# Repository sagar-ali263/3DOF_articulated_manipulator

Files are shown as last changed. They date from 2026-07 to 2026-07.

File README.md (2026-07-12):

# 3-DOF Articulated Robotic Manipulator (3R Serial Arm)

A fully analyzed and hardware-implemented 3-revolute-joint serial manipulator, built as an independent robotics project. The project covers the complete pipeline: mechanical design, kinematic and dynamic derivation, MATLAB simulation/validation, and embedded PID control on real hardware.

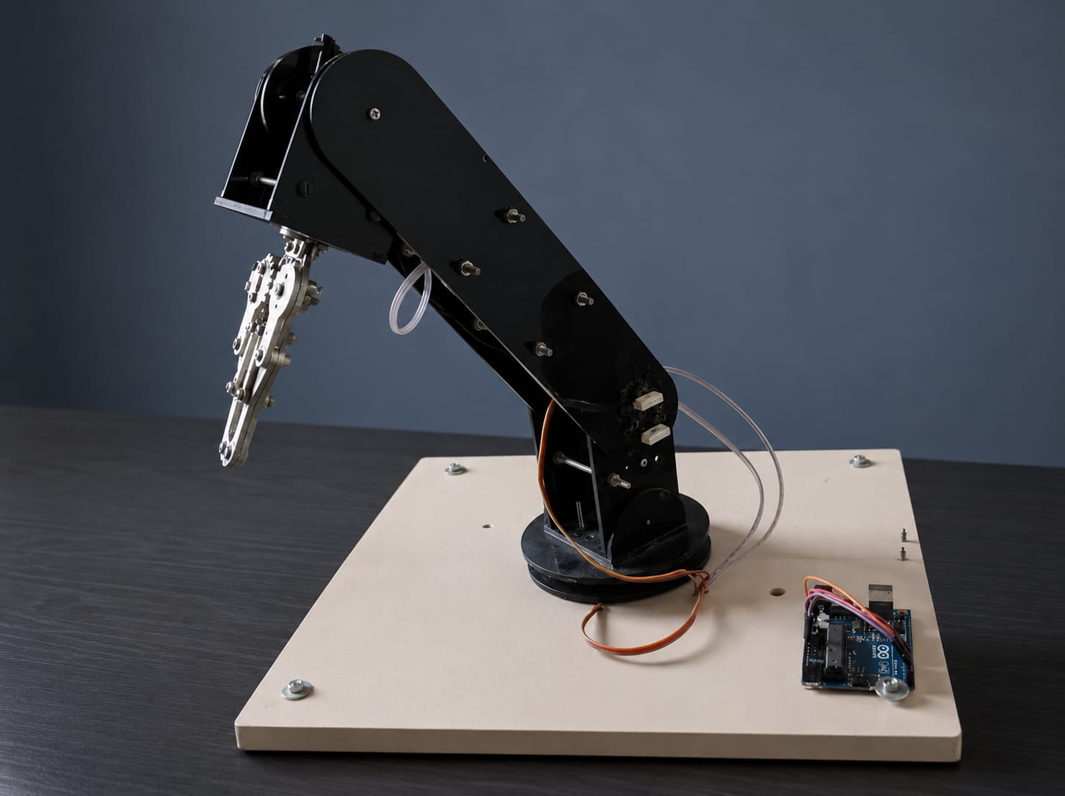
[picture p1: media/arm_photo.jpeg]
3DOF Manipulator


## Overview

- **Configuration:** RRR (3 revolute joints), open serial chain
- **Max vertical reach:** 470 mm
- **Actuators:** 3x MG995 metal gear servos (9.4 kg·cm @ 6V)
- **Controller:** ESP32, PWM servo control via the `ledc` peripheral (50 Hz, 14-bit resolution)
- **Design software:** SolidWorks (CAD/assembly), MATLAB Robotics System Toolbox (simulation), Arduino IDE (firmware)

## What's in this repo

| Folder | Contents |
|---|---|
| `cad/` | SolidWorks part/assembly files and STEP exports |
| `matlab/` | Kinematic, Jacobian, and dynamic simulation/validation scripts |
| `firmware/` | ESP32 Arduino code for PWM joint control |
| `docs/` | Full project report (PDF) with complete derivations |
| `media/` | Photos and demo video/GIF of the physical build |

## Technical Highlights

**Kinematics**
- Forward kinematics derived analytically using the Denavit-Hartenberg convention and homogeneous transformation matrices
- Verified against MATLAB's `rigidBodyTree` model, cross-checked at multiple joint-angle test configurations

**Jacobian and Singularity Analysis**
- Full geometric Jacobian derived manually (skew-symmetric matrix method) and independently verified against MATLAB's built-in `geometricJacobian`
- Two singularity conditions identified through determinant analysis: an elbow singularity (fully extended/folded arm) and a workspace-boundary singularity (end-effector on the vertical axis)
- Manipulability index (`w = sqrt(det(Jv * Jv'))`) computed across the reachable workspace to visualize dexterity and flag near-singular regions

**Dynamics**
- Full equations of motion derived via the Euler-Lagrange formulation, including per-link inertia tensors (parallel-axis theorem), the 3x3 mass matrix, Coriolis/centrifugal terms, and the gravity vector
- Mass matrix verified in MATLAB for symmetry and positive definiteness
- Joint torques (tau1, tau2, tau3) computed and cross-checked against the analytical derivation for a test trajectory

**Control**
- Joint-space PID control implemented on ESP32, mapping target joint angles to PWM pulse width (500-2500 microseconds)
- Software joint-limit enforcement and safe home-position initialization on power-up
- `checkTrajectoryPoint.m` used to reject unsafe trajectory waypoints that approach a singular configuration before sending them to hardware

## Validation Approach

Every analytical result in this project (forward kinematics, Jacobian, mass matrix, gravity vector, joint torques) was independently cross-checked against MATLAB's Robotics System Toolbox before being trusted, and the maximum numerical error was printed at each validation step. This was done deliberately: since the hardware implementation depends on this model being correct, each stage had to pass validation before moving to the next.

## Tools Used

SolidWorks - MATLAB (Robotics System Toolbox) - Arduino IDE - ESP32

## Full Report

See [`docs/`](./docs) for the complete project report, including all derivations, experimental workspace/manipulability plots, and the economic/safety/educational analysis.

---

*Sagar Ali - BS Mechatronics and Control Engineering, UET Lahore (Faisalabad Campus)*

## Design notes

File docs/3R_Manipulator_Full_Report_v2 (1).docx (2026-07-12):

UNIVERSITY LABORATORY REPORT

Design, Analysis and Fabrication of a

3R Serial Robotic Manipulator Arm

Submitted by:

[Student Name]

[Registration No.]

Supervised by:

[Supervisor Name]

Department of Mechatronics Engineering

May 2026

1. Key Characteristics

The manipulator under study is a three-revolute-joint (3R) serial robotic arm. Each joint is an actuated revolute joint making this a fully rotational, open-chain mechanism with three degrees of freedom. The principal characteristics are summarised in Table 1.

Table 1: Key Characteristics of the 3R Manipulator

Parameter | Value / Description
Configuration | RRR — three revolute joints in series (serial chain)
Degrees of Freedom | 3
Joint 1 — θ₁ | Rotation about vertical Z₀ axis (base rotation), range: 0° – 180°
Joint 2 — θ₂ | Rotation about horizontal Z₁ axis (shoulder), range: 0° – 180°
Joint 3 — θ₃ | Rotation about Z₂ axis (elbow), range: 0° – 180°
Base Height (d₁) | 90 mm — vertical offset from base frame to shoulder joint
Link 2 Length (l₂) | 210 mm
Link 3 Length (l₃) | 170 mm (includes end-effector body)
Maximum Reach | 380 mm from shoulder (l₂ + l₃, arm fully extended)
Minimum Reach | 40 mm (|l₂ − l₃|, arm fully folded)
End-Effector | Point at tip of Link 3 — no gripper
Actuators | MG995 Metal Gear Servo Motors × 3 (torque: 9.4 kg·cm @ 6 V)
Controller | ESP32 Microcontroller — PWM via ledc peripheral
Link Material | Acrylic (PMMA) sheet, 5 mm thick, ρ ≈ 1180 kg/m³
Design Software | SolidWorks
Analysis Software | MATLAB
Firmware IDE | Arduino IDE

2. Design

2.1 Mechanical Structure

The 3R manipulator consists of a fixed acrylic base plate, three MG995 servo motors acting as revolute joints, two flat acrylic link bars, and a point end-effector at the tip of Link 3. The base servo (Joint 1) is mounted vertically and rotates the entire arm assembly about the Z₀ axis. Link 1 is the rigid vertical column of height d₁ = 90 mm connecting the base to Joint 2. Link 2 (l₂ = 210 mm) is a flat acrylic bar connecting Joint 2 to Joint 3. Link 3 (l₃ = 170 mm) extends from Joint 3 to the end-effector point. A gripper-like profile visible at the end of Link 3 in the SolidWorks model is a structural feature of Link 3 only and carries no functional gripper purpose. All links are machined from 5 mm thick acrylic sheet.

[ INSERT IMAGE HERE ]

Figure 1: SolidWorks Assembly — 3R Manipulator (Isometric View)

2.2 Frame Assignment

Coordinate frames are assigned following the standard Denavit-Hartenberg convention. The Z-axis of each frame coincides with the joint rotation axis. The symbol ⊗ in the design sketches denotes a Z-axis directed out of the plane, confirming that Z₁ and Z₂ are horizontal and parallel. The base frame Z₀ points vertically upward.

[ INSERT IMAGE HERE ]

Figure 2: DH Frame Assignment Sketch (Side View with Z-axes and Origins labelled)

2.3 Home / Reference Configuration

Before executing any motion task the manipulator is driven to a fixed reference pose known as the home configuration. This ensures a consistent and safe starting state from which all trajectories are planned. The home joint angles are:

θ_1 = 0°, θ_2 = 0°, θ_3 = 90°

Substituting into the forward kinematics equations (derived in Section 4):

x = cos 0° · (210 cos 0° + 170 cos 90°) = 1 · (210 + 0) = 210 mm

y = sin 0° · (210 cos 0° + 170 cos 90°) = 0 mm

z = 90 + 210 sin 0° + 170 sin 90° = 90 + 0 + 170 = 260 mm

The end-effector point is therefore located at (210, 0, 260) mm in the base frame at the home position. Table 2 gives the corresponding PWM initialisation values for the ESP32.

Table 2: PWM Values at Home Configuration

Joint | Home Angle | PWM Pulse Width
Joint 1 (θ₁) | 0° | 500 μs
Joint 2 (θ₂) | 0° | 500 μs
Joint 3 (θ₃) | 90° | 1500 μs

The PWM frame frequency is 50 Hz. Pulse widths range from 500 μs (0°) to 2500 μs (180°) across all three servos. On power-up the ESP32 drives all channels to home values before accepting any motion commands.

[ INSERT IMAGE HERE ]

Figure 3: SolidWorks — Home Configuration (θ₁=0°, θ₂=0°, θ₃=90°) Side View

3. Homogeneous Transformation Matrices

A homogeneous transformation matrix T ∈ ℝ⁴ˣ⁴ encodes the rotation and translation from one coordinate frame to the adjacent frame. Using the standard Denavit-Hartenberg convention, the transformation between frames i−1 and i is:

T_(i−1)^i = Rot(Z, θ_i ) · Trans(Z, d_i ) · Trans(X, a_i ) · Rot(X, α_i )

Expanding into matrix form, where cθ = cosθ, sθ = sinθ, cα = cosα, sα = sinα:

T = [cθᵢ, −sθᵢcαᵢ, sθᵢsαᵢ, aᵢcθᵢsθᵢ, cθᵢcαᵢ, −cθᵢsαᵢ, aᵢsθᵢ0, sαᵢ, cαᵢ, dᵢ0, 0, 0, 1]

The shorthand notation cᵢ = cosθᵢ, sᵢ = sinθᵢ, c₂₃ = cos(θ₂+θ₃), s₂₃ = sin(θ₂+θ₃) is used throughout.

3.1 Individual Transformation Matrix T₀¹ (Joint 1)

Parameters: a₁ = 0, α₁ = 90° ⟹ cosα₁ = 0, sinα₁ = 1, d₁ = 90 mm, θ₁ variable.

⁰T₁ = [c₁, 0, s₁, 0s₁, 0, −c₁, 00, 1, 0, 900, 0, 0, 1]

3.2 Individual Transformation Matrix T₁² (Joint 2)

Parameters: a₂ = 210 mm, α₂ = 0° ⟹ cosα₂ = 1, sinα₂ = 0, d₂ = 0, θ₂ variable.

¹T² = [c₂, −s₂, 0, 210c₂s₂, c₂, 0, 210s₂0, 0, 1, 00, 0, 0, 1]

3.3 Individual Transformation Matrix T₂³ (Joint 3)

Parameters: a₃ = 170 mm, α₃ = 0°, d₃ = 0, θ₃ variable.

²T³ = [c₃, −s₃, 0, 170c₃s₃, c₃, 0, 170s₃0, 0, 1, 00, 0, 0, 1]

3.4 Cumulative Matrix ⁰T² = ⁰T¹ · ¹T²

Multiplying row by column and applying c₁c₂ − s₁s₂ = c₂₃ where appropriate:

Element-by-element computation (row 1, column 1):

R(1,1) = c₁·c₂ + 0·s₂ + s₁·0 = c₁c₂

Element (1,4) — position x:

p_x = c₁·210c₂ + 0·210s₂ + s₁·0 + 0 = 210c₁c₂

Element (3,4) — position z:

p_z = 0·210c₂ + 1·210s₂ + 0·0 + 90 = 210s₂ + 90

Full result:

⁰T² = [c₁c₂, −c₁s₂, s₁, 210c₁c₂s₁c₂, −s₁s₂, −c₁, 210s₁c₂s₂, c₂, 0, 210s₂+900, 0, 0, 1]

3.5 Full End-Effector Transform ⁰T³ = ⁰T² · ²T³

Multiplying ⁰T² by ²T³. Using the angle-sum identities:

c₂c₃ − s₂s₃ = cos(θ₂+θ₃) = c₂₃

s₂c₃ + c₂s₃ = sin(θ₂+θ₃) = s₂₃

Key element computations:

R(1,1) = c₁c₂·c₃ + (−c₁s₂)·s₃ = c₁(c₂c₃−s₂s₃) = c₁c₂₃

R(1,2) = c₁c₂·(−s₃) + (−c₁s₂)·c₃ = −c₁(c₂s₃+s₂c₃) = −c₁s₂₃

p_x = 170c₁(c₂c₃−s₂s₃) + 210c₁c₂ = c₁(210c₂ + 170c₂₃)

p_z = 170(s₂c₃+c₂s₃) + 210s₂ + 90 = 90 + 210s₂ + 170s₂₃

Final result:

⁰T³ = [c₁c₂₃, −c₁s₂₃, s₁, c₁(210c₂+170c₂₃)s₁c₂₃, −s₁s₂₃, −c₁, s₁(210c₂+170c₂₃)s₂₃, c₂₃, 0, 90+210s₂+170s₂₃0, 0, 0, 1]

4. Forward Position Kinematics

Forward kinematics maps a set of joint angles (θ₁, θ₂, θ₃) to the Cartesian position (x, y, z) of the end-effector point O₃ in the base frame. The position is extracted from the fourth column of ⁰T³.

4.1 DH Parameter Table

Table 3: Denavit-Hartenberg Parameters

Joint i | aᵢ (mm) | αᵢ (deg) | dᵢ (mm) | θᵢ (variable)
1 | 0 | 90° | d₁ = 90 | θ₁* (0° – 180°)
2 | l₂ = 210 | 0° | 0 | θ₂* (0° – 180°)
3 | l₃ = 170 | 0° | 0 | θ₃* (0° – 180°)

The asterisk (*) marks the variable (active) joint parameter. All remaining entries in each row are constant geometric properties of the link.

4.2 Forward Kinematics Equations

Extracting the position column of ⁰T³, the end-effector position O₃ is:

x = c_1 · (210c_2 + 170c_23 )

y = s_1 · (210c_2 + 170c_23 )

z = 90 + 210s_2 + 170s_23

The x and y coordinates share the same horizontal radius r = 210c₂ + 170c₂₃, scaled by cosθ₁ and sinθ₁ respectively. This confirms that joint 1 sweeps the arm through the horizontal plane while joints 2 and 3 control vertical elevation.

4.3 Verification at Home Configuration

At θ₁ = 0°, θ₂ = 0°, θ₃ = 90° (home position):

x = cos0°·(210cos0° + 170cos90°) = 1·(210 + 0) = 210 mm

y = sin0°·(210cos0° + 170cos90°) = 0 mm

z = 90 + 210sin0° + 170sin90° = 90 + 0 + 170 = 260 mm

Result: O₃ = (210, 0, 260) mm — consistent with the home configuration derived in Section 2.3.

5. Inverse Position Kinematics

Inverse kinematics (IK) computes the joint angles (θ₁, θ₂, θ₃) given a desired end-effector position (x_d, y_d, z_d). Two complementary approaches are presented below.

Define the following intermediate variables used by both approaches:

r = √(x^2 ₝ + y^2 ₞) [horizontal distance from Z₀ axis]

s = z_d − d_1 = z_d − 90 [height above Joint 2]

5.1 Algebraic Approach

Step 1 — Solve for θ₁

From the FK equations x = c₁·r and y = s₁·r. Dividing y by x:

tanθ_1 = (y_d)/(x_d)

θ_1 = atan2 (y_d , x_d )

The four-quadrant atan2 function is used to correctly handle all quadrants. The joint range 0°–180° restricts valid solutions to y_d ≥ 0.

Step 2 — Solve for θ₃

Squaring and adding the planar FK equations for r and s:

r = 210c_2 + 170c_23

s = 210s_2 + 170s_23

r^2 + s^2 = (210c_2 +170c_23 )^2 + (210s_2 +170s_23 )^2

Expanding and collecting using c₂c₂₃ + s₂s₂₃ = cos(θ₃):

= 210² + 170² + 2·210·170·cosθ₃

= 44100 + 28900 + 71400 cosθ₃

= 73000 + 71400 cosθ₃

Therefore:

cosθ_3 = (r^2 + s^2 − 73000)/71400

θ_3 = ± arccos[(r^2 + s^2 − 73000)/71400]

Two solutions exist: θ₃ > 0 (elbow-up) and θ₃ < 0 (elbow-down). A real solution exists only when |cosθ₃| ≤ 1, i.e. the target lies within the reachable workspace.

Step 3 — Solve for θ₂ (algebraic substitution)

Expanding the FK equations for r and s with θ₃ now known:

r = (210 + 170c₃)c₂ − 170s₃·s₂ = k₁c₂ − k₂s₂

s = (210 + 170c₃)s₂ + 170s₃·c₂ = k₁s₂ + k₂c₂

where the substitution constants are:

k_1 = 210 + 170c_3

k_2 = 170s_3

Solving simultaneously:

θ_2 = atan2(k_1 s − k_2 r , k_1 r + k_2 s)

5.2 Geometric Approach

Step 1 — θ₁ (identical to algebraic)

θ_1 = atan2(y_d , x_d )

Step 2 — Distance D and θ₃ via Law of Cosines

In the vertical (r, s) plane, D is the distance from Joint 2 to the end-effector:

D = √(r^2 + s^2)

Applying the law of cosines to the triangle with sides l₂, l₃ and hypotenuse D:

D² = l₂² + l₃² − 2l₂l₃cos(180°−θ₃) = 44100 + 28900 + 71400cosθ₃

cosθ_3 = (D^2 − 73000)/71400

Step 3 — Angles β and γ for θ₂

β is the elevation angle of the line from Joint 2 to the end-effector:

β = atan2(s , r)

γ is the interior angle at Joint 2, from the law of cosines:

cosγ = (l^2 ₂ + D^2 − l^2 ₃)/(2l_2 D) = (D^2 + 15200)/(420D)

γ = arccos[(D^2 + 15200)/(420D)]

The shoulder angle θ₂ is then:

θ_2 = β − γ [elbow-up solution]

θ_2 = β + γ [elbow-down solution]

6. Velocity Kinematics

Velocity kinematics relates joint angular velocities to the linear and angular velocity of the end-effector through the Jacobian matrix J. The explicit geometric Jacobian method is used, following the instructor’s step-by-step procedure.

[ṻₑωₑ] = J · [θ̇₁θ̇₂θ̇₃]

6.1 Step 1: Extract Z-axis Vectors from Cumulative T Matrices

The Z-axis vector Zᵢ is the third column of the rotation sub-matrix of ⁰Tᵢ. From the matrices derived in Section 3:

Z_0 = [001]

(base frame Z-axis, pointing vertically upward)

Z_1 = Third column of R in ⁰T¹ = [s_1 −c_1 0]

Z_2 = Third column of R in ⁰T² = [s_1 −c_1 0]

Note: Z₁ = Z₂ because α₂ = 0° introduces no twist between frames 1 and 2.

6.2 Step 2: Extract Origin Vectors from Cumulative T Matrices

The origin Oᵢ is the fourth column (position vector) of ⁰Tᵢ:

O_0 = [000]

O_1 = [0090]

O_2 = [210c_1 c_2 210s_1 c_2 90 + 210s_2 ]

End-effector origin (from ⁰T³):

O_3 = [c_1 (210c_2 +170c_23 )s_1 (210c_2 +170c_23 )90+210s_2 +170s_23 ]

6.3 Step 3: Skew-Symmetric Matrices S(Z)

The instructor requires that the cross product Z × v be written as S(Z)·v, where the skew-symmetric matrix of Z = [z_x, z_y, z_z]ᵀ is:

S(Z) = [0, −z_z, z_yz_z, 0, −z_x−z_y, z_x, 0]

S(Z₀) — for Joint 1

Z₀ = [0, 0, 1]ᵀ ⟹ z_x=0, z_y=0, z_z=1

S(Z₀) = [0, − 1, 01, 0, 00, 0, 0]

S(Z₁) — for Joint 2

Z₁ = [s₁, −c₁, 0]ᵀ ⟹ z_x=s₁, z_y=−c₁, z_z=0

S(Z₁) = [0, 0, −c₁0, 0, −s₁c₁, s₁, 0]

S(Z₂) — for Joint 3

Z₂ = [s₁, −c₁, 0]ᵀ (same as Z₁)

S(Z₂) = S(Z₁) = [0, 0, −c₁0, 0, −s₁c₁, s₁, 0]

6.4 Step 4: Compute O₃ − Oᵢ (Full Subtraction, No Premature Cancellation)

Let P = 210c₂ + 170c₂₃ and Q = 210s₂ + 170s₂₃ for conciseness.

O₃ − O₀

O_3 − O_0 = [c_1 P − 0s_1 P − 090+Q − 0]

= [c_1 Ps_1 P90 + Q]

O₃ − O₁

O_3 − O_1 = [c_1 P − 0s_1 P − 0(90+Q) − 90]

= [c_1 Ps_1 PQ]

O₃ − O₂

O_3 − O_2 = [c_1 (210c₂+170c₂₃) − 210c_1 c_2 s_1 (210c₂+170c₂₃) − 210s_1 c_2 (90+Q) − (90+210s₂)]

Expanding and grouping identical terms:

Row 1: 210c₁c₂ + 170c₁c₂₃ − 210c₁c₂ = (210c₁c₂ − 210c₁c₂) + 170c₁c₂₃ = 170c₁c₂₃

Row 2: 210s₁c₂ + 170s₁c₂₃ − 210s₁c₂ = (210s₁c₂ − 210s₁c₂) + 170s₁c₂₃ = 170s₁c₂₃

Row 3: 90+210s₂+170s₂₃−90−210s₂ = (90−90)+(210s₂−210s₂)+170s₂₃ = 170s₂₃

O_3 − O_2 = [170c_1 c_23 170s_1 c_23 170s_23 ]

6.5 Step 5: Compute Linear Jacobian Columns Jᵥᵢ = S(Zᵢ₋₁)(O₃−Oᵢ₋₁)

Column 1: Jᵥ₁ = S(Z₀)(O₃−O₀)

Performing the matrix–vector multiplication row by row:

Row 1: (0)(c₁P) + (−1)(s₁P) + (0)(90+Q) = −s₁P

Row 2: (1)(c₁P) + (0)(s₁P) + (0)(90+Q) = c₁P

Row 3: (0)(c₁P) + (0)(s₁P) + (0)(90+Q) = 0

J_(v1) = [−s₁P c₁P 0]

Column 2: Jᵥ₂ = S(Z₁)(O₃−O₁)

Row 1: (0)(c₁P) + (0)(s₁P) + (−c₁)(Q) = −c₁Q

Row 2: (0)(c₁P) + (0)(s₁P) + (−s₁)(Q) = −s₁Q

Row 3: (c₁)(c₁P) + (s₁)(s₁P) + (0)(Q) = c^2 ₁P + s^2 ₁P = P

J_(v2) = [−c₁Q−s₁Q P]

Column 3: Jᵥ₃ = S(Z₂)(O₃−O₂)

Row 1: (0)(170c₁c₂₃) + (0)(170s₁c₂₃) + (−c₁)(170s₂₃) = −170c₁s₂₃

Row 2: (0)(170c₁c₂₃) + (0)(170s₁c₂₃) + (−s₁)(170s₂₃) = −170s₁s₂₃

Row 3: (c₁)(170c₁c₂₃) + (s₁)(170s₁c₂₃) + (0)(170s₂₃) = 170c₂₃(c^2 ₁+s^2 ₁) = 170c₂₃

J_(v3) = [−170c₁s₂₃−170s₁s₂₃ 170c₂₃]

6.6 Step 6: Angular Jacobian Columns Jωᵢ = Zᵢ₋₁

For revolute joints the angular velocity contribution is simply the Z-axis of the previous frame:

Jω₁ = Z₀ = [0, 0, 1]ᵀ

Jω₂ = Z₁ = [s₁, −c₁, 0]ᵀ

Jω₃ = Z₂ = [s₁, −c₁, 0]ᵀ

6.7 Step 7: Full Geometric Jacobian J (6 × 3)

Assembling all columns (P = 210c₂+170c₂₃, Q = 210s₂+170s₂₃):

J = [−s₁P, −c₁Q, −170c₁s₂₃c₁P, −s₁Q, −170s₁s₂₃0, P, 170c₂₃0, s₁, s₁0, −c₁, −c₁1, 0, 0]

The upper three rows form the linear velocity Jacobian Jᵥ and the lower three rows form the angular velocity Jacobian Jω.

6.8 Analytical (Linear Velocity) Jacobian Jᵥ (3 × 3)

Jᵥ = [−s₁P, −c₁Q, −170c₁s₂₃c₁P, −s₁Q, −170s₁s₂₃0, P, 170c₂₃]

6.9 Singularity Analysis

A singularity occurs when the Jacobian loses rank, i.e. det(Jᵥ) = 0. The arm cannot generate end-effector velocity in one or more directions at a singular configuration.

Determinant Calculation — Cofactor Expansion Along Row 3

det(Jᵥ) = 0·C₃₁ + P·C₃₂ + 170c₂₃·C₃₃

Computing cofactor C₃₂:

C₃₂ = (−1)⁵ · det[ [−s₁P, −170c₁s₂₃], [c₁P, −170s₁s₂₃] ]

= −1 · [ (−s₁P)(−170s₁s₂₃) − (−170c₁s₂₃)(c₁P) ]

= −1 · [ 170s^2 ₁Ps₂₃ + 170c^2 ₁Ps₂₃ ]

= −1 · 170Ps₂₃(s^2 ₁+c^2 ₁) = −170Ps₂₃

Computing cofactor C₃₃:

C₃₃ = (+1) · det[ [−s₁P, −c₁Q], [c₁P, −s₁Q] ]

= (−s₁P)(−s₁Q) − (−c₁Q)(c₁P) = s^2 ₁PQ + c^2 ₁PQ = PQ

Therefore:

det(Jᵥ) = P·(−170Ps₂₃) + 170c₂₃·PQ

= 170P(−Ps₂₃ + c₂₃Q)

= 170P [ c₂₃(210s₂+170s₂₃) − s₂₃(210c₂+170c₂₃) ]

= 170P · 210 [ c₂₃s₂ − s₂₃c₂ ]

= 170 · 210 · P · sin(θ₂ − (θ₂+θ₃))

= −35700 · P · sinθ₃

det(Jᵥ) = −35700 · (210c_2 + 170c_23 ) · sinθ_3

Singular Configurations

The determinant vanishes under two independent conditions:

Singularity 1 — Elbow Singularity:

sinθ_3 = 0 ⟹ θ_3 = 0° or 180°

At θ₃ = 0° the arm is fully extended; at θ₃ = 180° the arm is fully folded. Joints 2 and 3 become collinear and lose one degree of independent control.

Singularity 2 — Workspace Boundary (Axis Alignment):

P = 0 ⟹ 210c_2 + 170c_23 = 0

The end-effector lies on the vertical Z₀ axis (r = 0). The azimuthal angle θ₁ becomes undefined and joint 1 is singular.

7. Dynamics

The equation of motion of a rigid-body serial manipulator, derived from the Euler-Lagrange formulation, is:

M(q)äq + C(q, ̇q) ̇q + G(q) = τ

where q = [θ₁, θ₂, θ₃]ᵀ is the joint vector, M(q) is the 3×3 mass matrix, C(q,̇q) is the Coriolis and centrifugal matrix, G(q) is the gravity vector, and τ is the joint torque vector.

Note: Physical link masses are to be measured experimentally and will be substituted into the symbolic expressions below. Placeholder symbols m₂, m₃ denote link masses and I₂, I₃ denote link moments of inertia.

7.1 Inertia Tensor of Each Link

Each acrylic link is modelled as a uniform rectangular bar of length l, width w, and thickness t. The inertia tensor about the link centre of mass (COM), with axes aligned with the principal body axes, is derived by direct integration:

Iᴄᴹ = [m(w²+t²)/12, 0, 00, m(l²+t²)/12, 00, 0, m(l²+w²)/12]

For thin acrylic sheet (t = 5 mm ≪ l, w), terms involving t² are negligible. The dominant inertia components are:

Link 2 (l₂ = 210 mm, mass m₂, width w₂):

I_(2yy) ≈ (m_2 l^2 ₂)/12 = 3675m_2 mm²

I_(2zz) ≈ (m_2 (l^2 ₂+w^2 ₂))/12

Link 3 (l₃ = 170 mm, mass m₃, width w₃):

I_(3yy) ≈ (m_3 l^2 ₃)/12 = 2408.3m_3 mm²

By the parallel-axis theorem (shifting from COM to proximal joint end):

I_(2,joint) = (m_2 l^2 ₂)/12 + m_2 ((l_2)/2)^2 = (m_2 l^2 ₂)/3 = 14700m_2 mm²

I_(3,joint) = (m_3 l^2 ₃)/3 = 9633.3m_3 mm²

7.2 Mass Matrix M(q)

Using the Lagrangian formulation T = ½̇qᵀ M(q) ̇q, the mass matrix is computed from the squared velocities of the link centres of mass. The total translational kinetic energy is:

T = ½ m_2 |v_(C2) |^2 + ½ m_3 |v_(C3) |^2 + rotational terms

After computing squared COM speeds and collecting terms by joint velocity products, the 3×3 symmetric mass matrix M(q) is:

M(q) = [M₁₁, 0, 00, M₂₂, M₂₃0, M₃₂, M₃₃]

with elements:

M_11 = m_2 (105c_2 )^2 + m_3 (210c_2 +85c_23 )^2

M_22 = m_2 ·105² + m_3 (210² + 2·210·85·c_3 + 85²) + I_(2,joint)

M_33 = m_3 ·85² + I_(3,joint) = 7225m_3 + I_(3,joint)

M_23 = M_32 = m_3 (7225 + 17850c_3 )

M_12 = M_13 = 0

The block-diagonal structure (M₁₂ = M₁₃ = 0) arises because joint 1 rotation about the vertical Z₀ axis does not couple inertially with joints 2 and 3 in the rotational component. The coupling M₂₃ depends on cosθ₃ and represents the inertial coupling between shoulder and elbow.

Table 4: Geometric Factors for Mass Matrix Elements

Element | Expression | Notes
M₁₁ | m₂(105c₂)² + m₃(210c₂+85c₂₃)² | Varies with θ₂, θ₃
M₂₂ | 11025m₂ + (44100+35700c₃+7225)m₃ + I₂ | Varies with θ₃
M₃₃ | 7225m₃ + I₃,joint | Configuration-independent
M₂₃ = M₃₂ | (7225 + 17850c₃)m₃ | Varies with θ₃, zero at θ₃=90°
M₁₂ = M₁₃ | 0 | No coupling with base rotation

8. Control

8.1 Basic Revision

PID Controller

A Proportional-Integral-Derivative (PID) controller produces a control output u(t) from the joint angle error e(t) = θ_d(t) − θ(t):

u(t) = K_p e(t) + K_i ∫e(t)dt + K_d (de)/(dt)

In discrete form (implemented on the ESP32 at sampling period Tₛ):

u[k] = K_p e[k] + K_i T_s Σe[k] + K_d (e[k] − e[k−1))/(T_s)

State-Space Representation

Single-joint dynamics in state-space form with state x = [θ, θ̇]ᵀ:

ẋ = Ax + Bu, y = Cx

A = [0, 10, −b/J], B = [ 01/J], C = [1 0]

where J is the effective moment of inertia at the joint and b is the viscous friction coefficient.

8.2 Robot Control Strategies

Joint-Space Control

The simplest strategy treats each joint independently with a PID loop. The ESP32 maps target angle to PWM pulse width linearly:

Pulse width (μs) = 500 + (θ_i)/(180°) × 2000

This approach ignores dynamic coupling between joints and is acceptable for slow, precise motions under light loading.

Computed Torque Method

The full dynamic model is inverted to linearise and decouple the system:

τ = M(q)(äq_d + K_d ė + K_p e) + C(q,̇q)̇q + G(q)

This cancels the nonlinear dynamics, reducing the closed-loop system to three decoupled linear second-order systems. Accurate values of M, C, G (requiring measured link masses) are needed.

Task-Space Control

The Cartesian position error drives the control via the Jacobian inverse:

̇q = J^v ⁻¹(ẋ_d + K_p (x_d − x_e ))

The pseudo-inverse Jᵥ⁺ = Jᵥᵀ(JᵥJᵥᵀ)⁻¹ is used near singular configurations. This strategy is preferred for straight-line trajectory tracking in Cartesian space.

ESP32 Implementation Notes

- PWM frame frequency: 50 Hz on all three servo channels.
- Pulse width range: 500 μs (0°) to 2500 μs (180°).
- Control loop runs on Core 1; serial communication and trajectory interpolation run on Core 0.
- The ledc peripheral provides 14-bit PWM resolution (≈0.01° per step).
- On power-up, all joints are driven to home position before accepting commands.
- Software joint-limit enforcement prevents commands outside the 0°–180° range.

9. Social and Economic Issues

9.1 Employment and Workforce Displacement

The increasing deployment of robotic manipulators in manufacturing and logistics raises concerns about workforce displacement. Repetitive assembly, welding, and pick-and-place tasks are most susceptible to automation. While robots reduce unit production cost and improve repeatability, they can displace semi-skilled workers in the short term. The economic consensus favours net long-term job creation through new industries such as robot manufacturing, programming, and maintenance, but the transition period requires retraining programmes and active policy support.

9.2 Safety

Robotic manipulators pose physical hazards including collision, pinch-point injuries, and unpredictable motion during faults. International standards (ISO 10218, ISO/TS 15066) mandate safety fencing, emergency stops, and force-torque limiting for collaborative robots. The 3R arm presented here operates at low torque (MG995 maximum 9.4 kg·cm) and low speed, placing it in the low-risk category. Safe operating zones, software joint-limit enforcement, and power-off-on-fault logic are implemented in the ESP32 firmware.

9.3 Economic Viability and Cost

A principal advantage of this design is its low cost relative to commercial 3-DOF arms. The bill of materials — three MG995 servos, acrylic sheet, ESP32 board, fasteners, and a power supply — totals approximately USD 15–25, compared with thousands of dollars for a commercial counterpart. This makes the platform accessible to university laboratories, STEM education programmes, and small-scale research groups in developing economies, democratising access to robotic manipulation technology.

9.4 Educational and Research Value

The project provides a tangible, hands-on platform for teaching kinematic theory (DH parameters, FK, IK), velocity analysis (Jacobian, singularities), and basic dynamics — concepts that are otherwise purely abstract in textbook form. Students engage directly with the gap between theoretical models and physical hardware constraints such as servo backlash, acrylic flex, and PWM resolution limitations.

9.5 Environmental Impact

Acrylic (PMMA) is a petrochemical-derived thermoplastic that is not readily biodegradable. Responsible disposal, recycling through specialist PMMA processors, or substitution with bio-based polymers should be considered at end-of-life. The low power consumption of the ESP32 and MG995 servos (total peak current below 3 A at 6 V, i.e. 18 W maximum) results in a minimal operational carbon footprint, especially when powered from renewable energy sources.

9.6 Intellectual Property and Open-Source Ethics

The design, firmware, and kinematic analysis developed in this project are intended for open academic dissemination. Sharing CAD files, MATLAB scripts, and Arduino code under an open-source licence (MIT or Creative Commons) promotes reproducibility and allows other researchers to build upon the work without intellectual property barriers — an important principle in publicly funded academic research.

References

[1] J. J. Craig, Introduction to Robotics: Mechanics and Control, 3rd ed. Pearson Prentice Hall, 2004.

[2] B. Siciliano, L. Sciavicco, L. Villani and G. Oriolo, Robotics: Modelling, Planning and Control. Springer, 2009.

[3] M. W. Spong, S. Hutchinson and M. Vidyasagar, Robot Modeling and Control, 2nd ed. Wiley, 2020.

[4] Espressif Systems, ESP32 Technical Reference Manual, v5.1, 2023. [Online]. Available: https://docs.espressif.com

[5] Tower Pro, MG995 Metal Gear Servo Datasheet, 2020.

[6] ISO 10218-1:2011, Robots and Robotic Devices — Safety Requirements for Industrial Robots. ISO, Geneva, 2011.

[7] International Federation of Robotics, World Robotics Report 2023. IFR, Frankfurt, 2023.

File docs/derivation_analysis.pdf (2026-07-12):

### 3R Articulated Manipulator

Key Characteristics:

The manipulator under study is a three-revolute-joint (3R) serial robotic arm. All three joints are actuated revolute joints, making this a fully rotational, open-chain mechanism with three degrees of freedom. The system is designed for educational demonstration of robotic kinematics, dynamics, and point-to-point positioning.

Table 1: Key Characteristics of the 3R Manipulator

Parameter | Value / Description
Configuration | RRR — three revolute joints connected in series (serial chain)
Degrees of Freedom (DOF) | 3
Joint 1 — θ₁ | Rotation about vertical Z₀ axis (base rotation), range: 0° – 180°
Joint 2 — θ₂ | Rotation about horizontal Z₁ axis (shoulder), range: 0° – 180°
Joint 3 — θ₃ | Rotation about Z₂ axis (elbow), range: 0° – 180°
Base Height (d₁) | 90 mm — vertical offset from ground to shoulder joint centre
Link 2 Length (l₂) | 210 mm
Link 3 Length (l₃) | 170 mm (includes end-effector structural body)
Maximum Vertical Reach | d₁ + l₂ + l₃ = 90 + 210 + 170 = 470 mm (arm fully extended upward, θ₂=90°, θ₃=0°)
Minimum Vertical Reach | d₁ + l₂ − l₃ = 90 + 210 − 170 = 130 mm (arm folded back, θ₂=90°, θ₃=180°)
End-Effector | Point at tip of Link 3 — no gripper; gripper profile is structural only
Actuators | MG995 Metal Gear Servo Motors × 3 — torque 9.4 kg·cm @ 6 V
Controller | ESP32 Microcontroller — PWM via ledc peripheral (14-bit resolution)
Link Material | Acrylic (PMMA) sheet — 5 mm thick, ρ ≈ 1180 kg/m³
Link Cross-Section | Width (z-axis) = 60 mm, Height (y-axis) = 55 mm for Links 2 & 3
Link 1 Cross-Section | Width (z-axis) = 60 mm, Horizontal (x-axis) = 55 mm, Height (y- axis) = 90 mm
Design Software | SolidWorks (3D CAD and assembly)
Analysis Software | MATLAB (kinematics simulation, workspace, plots)
Firmware IDE | Arduino IDE (ESP32 PWM servo control)

DH Frame Assignment

Coordinate frames are assigned following the standard Denavit-Hartenberg convention. The Z-axis of each frame coincides with the joint rotation axis. The symbol ⊗ in the design sketch denotes a Z-axis directed into the page. Z₀ points vertically upward. Z₁ and Z₂ are horizontal and parallel (both pointing out of the plane in the side-view sketch), consistent with α₁ = 90° at joint 1 and α₂ = α₃ = 0°.

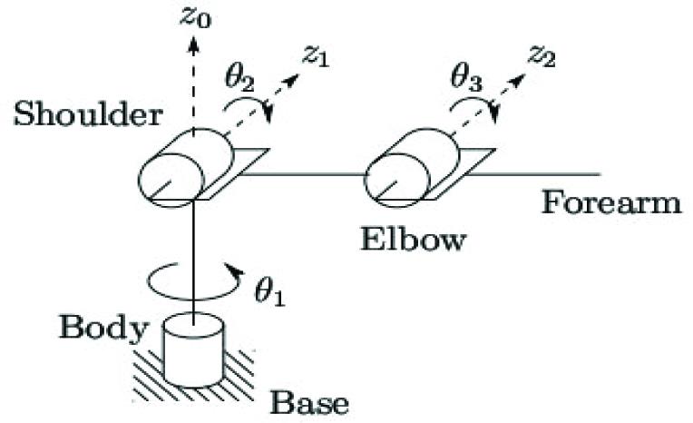
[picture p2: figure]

tt

Figure 2: DH Frame Assignment Sketch

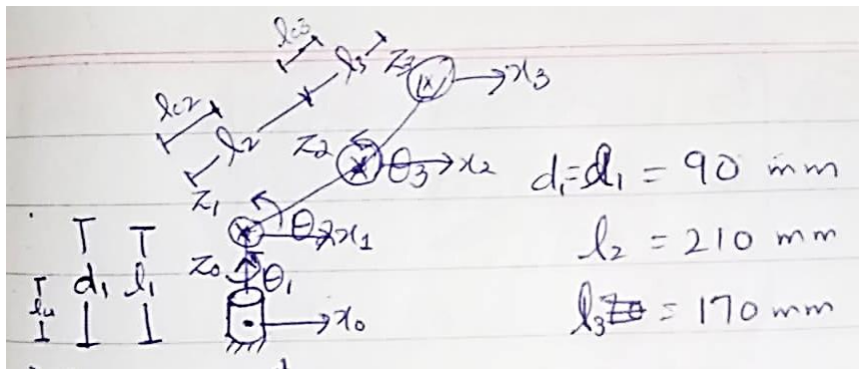
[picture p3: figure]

Home / Reference Configuration

Before executing any motion task, the manipulator is driven to a fixed reference pose known as the home configuration. This provides a consistent, safe starting state. The home joint angles are:

θ1 = 0° , θ2 = 0° , θ3 = 90°

Substituting into the forward kinematics (derived in Section 4): x = cos 0° · (210 cos 0° + 170 cos 90°) = 1 · (210 + 0) = 210 mm y = sin 0° · (210 cos 0° + 170 cos 90°) = 0 mm z = 90 + 210 sin 0° + 170 sin 90° = 90 + 0 + 170 = 260 mm

Home end-effector position: O₃ = (210, 0, 260) mm in the base frame.

Table 2: PWM Initialisation Values at Home Configuration

Joint | Home Angle | PWM Pulse Width
Joint 1 (θ₁) | 0° | 500 μs
Joint 2 (θ₂) | 0° | 500 μs
Joint 3 (θ₃) | 90° | 1500 μs

PWM frame frequency: 50 Hz. Range: 500 μs (0°) to 2500 μs (180°). On power-up, the ESP32 drives all channels to home values before accepting motion commands.

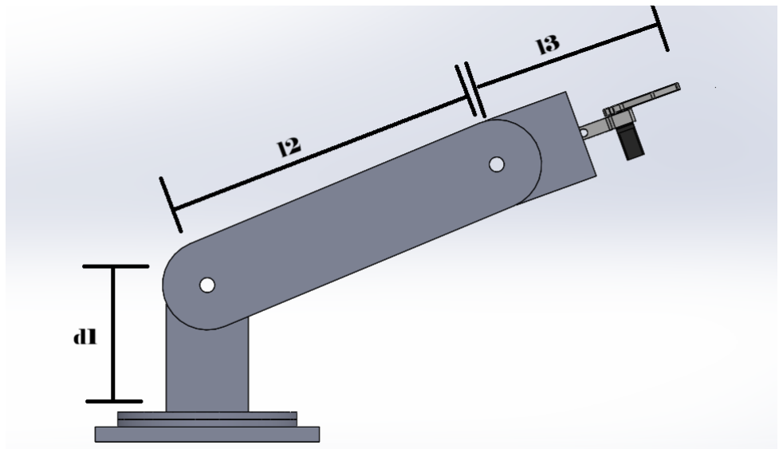
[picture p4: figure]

Homogeneous Transformation Matrices
A homogeneous transformation matrix T ∈ ℝ⁴ˣ⁴ encodes both the rotation and translation between two consecutive coordinate frames. Using the standard Denavit-Hartenberg convention, the transformation from frame i−1 to frame i is:

Tₘ = Rot(Z, θᵢ) · Trans(Z, dᵢ) · Trans(X, aᵢ) · Rot(X, αᵢ)

Expanding into 4×4 matrix form, where cθ = cosθ, sθ = sinθ, cα = cosα, sα = sinα:

Tᵢ = [

cθᵢ −sθᵢ cαᵢ | sθᵢ sαᵢ | aᵢ cθᵢ
sθᵢ cθᵢ cαᵢ | −cθᵢ sαᵢ aᵢ sθᵢ
0 | sαᵢ | cαᵢ | dᵢ
0 | 0 | 0 | 1

]

The shorthand notation cᵢ = cosθᵢ, sᵢ = sinθᵢ, c₂₃ = cos(θ₂+θ₃), s₂₃ = sin(θ₂+θ₃) is used throughout.

Individual Matrix ⁰T¹ (a₁=0, α₁=90°, d₁=90, θ₁)
Substituting a₁=0, α₁=90° ⟹ cosα₁=0, sinα₁=1, d₁=90 mm:

⁰T¹ = [

c₁ 0 | s₁ | 0
s₁ 0 | −c₁ | 0
0 | 1 | 0 | 90
0 | 0 | 0 | 1

]

Individual Matrix ¹T² (a₂=210, α₂=0°, d₂=0, θ₂) Substituting a₂=210 mm, α₂=0° ⟹ cosα₂=1, sinα₂=0, d₂=0:

¹T² = [

c₂ | −s₂ 0 210c₂
s₂ | c₂ | 0 210s₂
0 | 0 | 1 | 0
0 | 0 | 0 | 1

]

Individual Matrix ²T³ (a₃=170, α₃=0°, d₃=0, θ₃)

Substituting a₃=170 mm, α₃=0°, d₃=0:

²T³ = [

c₃ | −s₃ 0 170c₃
s₃ | c₃ | 0 170s₃
0 | 0 | 1 | 0
0 | 0 | 0 | 1

]

Cumulative Matrix ⁰T² = ⁰T¹ · ¹T²

Performing full row-by-column multiplication. Key element computations: R(1,1) = c₁ · c₂ + 0 · s₂ + s₁ · 0 = c₁c₂

R(2,1) = s₁ · c₂ + 0 · s₂ + (−c₁) · 0 = s₁c₂ R(3,1) = 0 · c₂ + 1 · s₂ + 0 · 0 = s₂ R(1,2) = c₁ · (−s₂) + 0 · c₂ + s₁ · 0 = −c₁s₂ R(1,3) = c₁ · 0 + 0 · 0 + s₁ · 1 = s₁ R(2,3) = s₁ · 0 + 0 · 0 + (−c₁) · 1 = −c₁
p_x = c₁ · 210c₂ + 0 · 210s₂ + s₁ · 0 + 0 = 210c₁c₂ p_y = s₁ · 210c₂ + 0 · 210s₂ + (−c₁) · 0 + 0 = 210s₁c₂ p_z = 0 · 210c₂ + 1 · 210s₂ + 0 · 0 + 90 = 210s₂ + 90

Full result:
⁰T² = [
c₁c₂ −c₁s₂ | s₁ | 210c₁c₂
s₁c₂ −s₁s₂ −c₁ | 210s₁c₂
s₂ | c₂ | 0 | 210s₂ + 90
0 | 0 | 0 | 1

]

Full End-Effector Transform ⁰T³ = ⁰T² · ²T³

Using the angle-sum identities: c₂c₃−s₂s₃ = c₂₃ and s₂c₃+c₂s₃ = s₂₃. Key element derivations: R(1,1) = c₁c₂ · c₃ + (−c₁s₂) · s₃ + s₁ · 0 = c₁(c₂c₃ − s₂s₃) = c₁c₂₃ R(1,2) = c₁c₂ · (−s₃) + (−c₁s₂) · c₃ = −c₁(c₂s₃ + s₂c₃) = −c₁s₂₃ R(2,1) = s₁c₂c₃ − s₁s₂s₃ = s₁c₂₃ R(3,1) = s₂c₃ + c₂s₃ = s₂₃ p_x = 170c₁c₂₃ + 210c₁c₂ = c₁(210c₂ + 170c₂₃)
p_y = 170s₁c₂₃ + 210s₁c₂ = s₁(210c₂ + 170c₂₃)
p_z = 170(s₂c₃ + c₂s₃) + 210s₂ + 90 = 90 + 210s₂ + 170s₂₃

Final result:
⁰T³ = [
c₁c₂₃ −c₁s₂₃ | s₁ | c₁(210c₂ + 170c₂₃)
s₁c₂₃ −s₁s₂₃ −c₁ | s₁(210c₂ + 170c₂₃)
s₂₃ | c₂₃ | 0 | 90 + 210s₂ + 170s₂₃
0 | 0 | 0 | 1

]

Forward Position Kinematics:

Forward kinematics maps a set of joint angles (θ₁, θ₂, θ₃) to the Cartesian position of the end-effector point O₃ in the base frame. The position is extracted from the fourth column of ⁰T³.

DH Parameter Table

Table 3: Denavit-Hartenberg Parameters

Joint i | aᵢ (mm) | αᵢ (deg) | dᵢ (mm) | θᵢ
1 | 0 | 90° | d₁ = 90 | θ₁* (0° – 180°)
2 | l₂ = 210 | 0° | 0 | θ₂* (0° – 180°)
3 | l₃ = 170 | 0° | 0 | θ₃* (180° – 180°)

The asterisk (*) marks the variable (active) parameter. All other entries per row are constant geometric properties of the link.

Forward Kinematics Equations

Extracting the position column of ⁰T³, the end-effector position O₃ = (x, y, z) in the base frame is:

x = c1 · ( 210c2 + 170c23 ) y = s1 · ( 210c2 + 170c23 ) z = 90 + 210s2 + 170s23

Physical interpretation: x and y share the same horizontal planar radius r = 210c₂ + 170c₂₃, scaled by cosθ₁ and sinθ₁ respectively. Joint 1 sweeps the arm through the horizontal plane; joints 2 and 3 control elevation.

Velocity Kinematics:

Velocity kinematics relates joint angular velocities to the end-effector linear and angular velocities through the Jacobian matrix. The instructor’s explicit geometric Jacobian method is followed throughout, using skew-symmetric matrix notation S(Z) in place of direct cross products.

Jacobian Method Overview

For each revolute joint i, the Jacobian column is: Jvi = S(Z i−1) · (O₃ − O i−1) [linear velocity contribution]
Jωi = Z i−1 | [angular velocity contribution]

where S(Z) is the skew-symmetric matrix of Z = [z_x, z_y, z_z]ᵀ:

S(Z) = [

0 | −z_z | z_y
z_z | 0 | −z_x
−z_y | z_x | 0

]

The end-effector position is denoted O₃ (not P). All subtractions O₃−Oᵢ are performed term-by-term without premature cancellation.

Step 1: Z-Axis Vectors (from ⁰Tᵢ rotation column 3) Z0 = [

0
0/1]

Z1 = Tℎird column of R in ⁰T¹ = [

s₁
−c₁
0

]

Z2 = Tℎird column of R in ⁰T² = [

s₁
−c₁
0

]

Note: Z₁ = Z₂ because α₂ = 0° introduces no twist between frames 1 and 2.

Step 2: Origin Vectors (from ⁰Tᵢ position column 4)
O0 = [

0
0/0]

O1 = [

0
0/90]

O2 = [

210c₁c₂
210s₁c₂
90 + 210s₂

]

O3 = [

c₁(210c₂ + 170c₂₃)
s₁(210c₂ + 170c₂₃)
90 + 210s₂ + 170s₂₃

]

Step 3: Skew-Symmetric Matrices S(Z)

S(Z₀): Z₀ = [0, 0, 1]ᵀ ⟹ z_x=0, z_y=0, z_z=1 S(Z₀) = [

0 −1 0
1 | 0 | 0
0 | 0 | 0

]

S(Z₁): Z₁ = [s₁, −c₁, 0]ᵀ ⟹ z_x=s₁, z_y=−c₁, z_z=0 S(Z₁) = [

0 | 0 −c₁
0 | 0 −s₁
c₁ s₁ | 0

]

S(Z₂) = S(Z₁) (same vector) S(Z₂) = [

0 | 0 −c₁
0 | 0 −s₁
c₁ s₁ | 0

]

O₃ − Oᵢ Subtractions (term by term, no premature cancellation)

Define shorthand: P = 210c₂ + 170c₂₃ and Q = 210s₂ + 170s₂₃.

O₃ − O₀
Row 1: c₁P − 0 = c₁P
Row 2: s₁P − 0 = s₁P
Row 3: (90 + Q) − 0 = 90 + Q O3 − O0 = [

c₁P
s₁P
90 + Q

]

O₃ − O₁
Row 1: c₁P − 0 = c₁P
Row 2: s₁P − 0 = s₁P
Row 3: (90 + Q) − 90 = Q
O3 − O1 = [

c₁P
s₁P
Q

]

O₃ − O₂
Row 1: c₁(210c₂ + 170c₂₃) − 210c₁c₂ = 210c₁c₂ + 170c₁c₂₃ − 210c₁c₂ = (210c₁c₂ − 210c₁c₂) + 170c₁c₂₃ = 170c₁c₂₃ Row 2: s₁(210c₂ + 170c₂₃) − 210s₁c₂ = (210s₁c₂ − 210s₁c₂) + 170s₁c₂₃ = 170s₁c₂₃
Row 3: (90 + Q) − (90 + 210s₂) = (90 − 90) + (210s₂ + 170s₂₃ − 210s₂) = (210s₂ − 210s₂) + 170s₂₃ = 170s₂₃

O3 − O2 = [

170c₁c₂₃
170s₁c₂₃

170s₂₃ ]

Step 5: Linear Jacobian Columns Jᵥᵢ = S(Zᵢ₋₁)(O₃−Oᵢ₋₁)

Column 1: Jᵥ₁ = S(Z₀)·(O₃−O₀)
Full row-by-row multiplication:
Row 1: (0)(c₁P) + (−1)(s₁P) + (0)(90 + Q) = −s₁P Row 2: (1)(c₁P) + (0)(s₁P) + (0)(90 + Q) = c₁P Row 3: (0)(c₁P) + (0)(s₁P) + (0)(90 + Q) = 0 Jv1 = [

−s₁P
c₁P
0

]

Column 2: Jᵥ₂ = S(Z₁)·(O₃−O₁)
Row 1: (0)(c₁P) + (0)(s₁P) + (−c₁)(Q) = −c₁Q Row 2: (0)(c₁P) + (0)(s₁P) + (−s₁)(Q) = −s₁Q Row 3: (c₁)(c₁P) + (s₁)(s₁P) + (0)(Q) = c₁²P + s₁²P = P(c₁² + s₁²) = P Jv2 = [

−c₁Q
−s₁Q
P

]

Column 3: Jᵥ₃ = S(Z₂)·(O₃−O₂) Row 1: (0)(170c₁c₂₃) + (0)(170s₁c₂₃) + (−c₁)(170s₂₃) = −170c₁s₂₃ Row 2: (0)(170c₁c₂₃) + (0)(170s₁c₂₃) + (−s₁)(170s₂₃) = −170s₁s₂₃ Row 3: (c₁)(170c₁c₂₃) + (s₁)(170s₁c₂₃) + (0)(170s₂₃) = 170c₂₃(c₁² + s₁²) = 170c₂₃
Jv3 = [

−170c₁s₂₃
−170s₁s₂₃

170c₂₃ ]

Step 6: Angular Jacobian Columns Jωᵢ = Zᵢ₋₁ Jω₁ = Z₀ = [0, 0, 1]ᵀ
Jω₂ = Z₁ = [s₁, −c₁, 0]ᵀ
Jω₃ = Z₂ = [s₁, −c₁, 0]ᵀ

Step 7: Full Geometric Jacobian J (6×3)
Assembling all columns, where P = 210c₂+170c₂₃ and Q = 210s₂+170s₂₃:

J =
[

−s₁P −c₁Q −170c₁s₂₃ ← v_x
c₁P | −s₁Q −170s₁s₂₃ ← v_y
0 | P | 170c₂₃ | ← v_z
0 | s₁ | s₁ | ← ω_x
0 | −c₁ | −c₁ | ← ω_y
1 | 0 | 0 | ← ω_z]

Analytical (Linear Velocity) Jacobian Jᵥ (3×3)

The upper 3×3 sub-matrix gives the linear velocity mapping ẋ = Jᵥ θ̇: Jᵥ = [

−s₁P −c₁Q −170c₁s₂₃
c₁P | −s₁Q −170s₁s₂₃
0 | P | 170c₂₃ ]

Singularity Analysis

A singularity occurs when det(Jᵥ) = 0. The arm cannot generate velocity in all directions at such configurations.

Determinant Calculation — Cofactor Expansion Along Row 3 det(Jᵥ) = 0 · C₃₁ + P · C₃₂ + 170c₂₃ · C₃₃

Cofactor C₃₂:
C₃₂ = (−1)⁵ det[[−s₁P, −170c₁s₂₃],[c₁P, −170s₁s₂₃]] = −1 · [(−s₁P)(−170s₁s₂₃) − (−170c₁s₂₃)(c₁P)] = −1 · [170s₁²Ps₂₃ + 170c₁²Ps₂₃]
= −1 · 170Ps₂₃(s₁² + c₁²) = −170Ps₂₃

Cofactor C₃₃:
C₃₃ = (+1) det[[−s₁P, −c₁Q],[c₁P, −s₁Q]] = (−s₁P)(−s₁Q) − (−c₁Q)(c₁P)
= s₁²PQ + c₁²PQ = PQ(s₁² + c₁²) = PQ

Substituting:
det(Jᵥ) = P · (−170Ps₂₃) + 170c₂₃ · PQ = 170P(−Ps₂₃ + Qc₂₃)

= 170P[c₂₃(210s₂ + 170s₂₃) − s₂₃(210c₂ + 170c₂₃)] = 170P · 210[c₂₃s₂ − s₂₃c₂]
= 170 · 210 · P · sin(θ₂ − (θ₂ + θ₃)) = −35700 · P · sinθ₃

det(Jᵥ) = −35700 · (210c₂ + 170c₂₃) · sinθ₃

Singular Configurations:

Singularity 1 — Elbow Singularity:
sinθ₃ = 0 ⟹ θ₃ = 0° or θ₃ = 180°

At θ₃=0° the arm is fully extended; at θ₃=180° it is fully folded. Joints 2 and 3 become collinear and lose one independent control direction in the (r,z) plane.

Singularity 2 — Workspace Boundary:
P = 0 ⟹ 210c₂ + 170c₂₃ = 0

The end-effector lies on the vertical Z₀ axis (r = 0). The azimuthal angle θ₁ is undefined and joint 1 becomes singular. Any θ₁ can produce the same x=y=0 position.

Dynamics:

The equation of motion of the 3R manipulator, derived from the Euler-Lagrange formulation, is: M(q)äq + B(q)[̇q̇q] + C(q)[̇q²] + G(q) = τ

where q = [θ₁,θ₂,θ₃]ᵀ is the joint vector, M(q) is the 3×3 symmetric mass matrix, B(q) is the Coriolis matrix, C(q) is the centrifugal matrix, G(q) is the gravity vector, and τ is the joint torque vector.

Inertia Tensor — Link 1

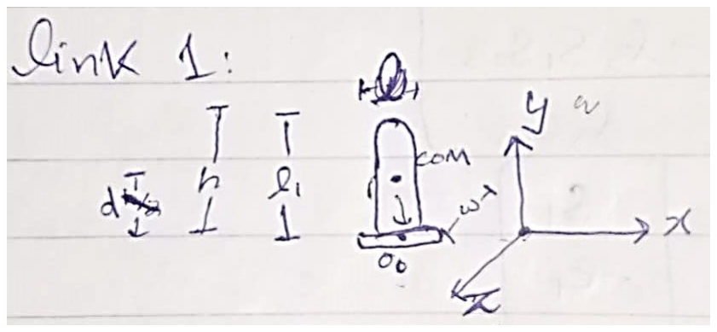
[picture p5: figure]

Link 1 is the vertical column. Its dimensions in the Cartesian frame are:

- a₁ = 55 mm (along x, horizontal)
- b₁ = 90 mm (along y, vertical — this is the link length)
- c₁ = 60 mm (along z, out of plane)

The inertia tensor at the centre of mass (COM), derived by direct triple integration over limits −a₁/2 to a₁/2 in x, −b₁/2 to b₁/2 in y, −c₁/2 to c₁/2 in z:

General derivation of I_xx (same procedure for other components):
Ixx = ρ ∫ ∫ ∫ (y² + z²) dV
= ρ ∫ ₋¹/²ᵃ ∫ ₋ᵇ/²ᵇ/² ∫ ₋ᶜ/²ᶜ/² (y² + z²) dz dy dx = ρ · a · ∫ ₋ᵇ/²ᵇ/² [y²z + z³/3]₋ᶜ/²ᶜ/² dy = ρ · a · ∫ ₋ᵇ/²ᵇ/² (y²c + c³/12) dy
= ρ · a · [cy³/3 + c³y/12]₋ᵇ/²ᵇ/²
= ρ · a · (cb³/12 + c³b/12) = ρ · abc · (b² + c²)/12 = m(b² + c²)/12

Applying to Link 1 (a₁=55, b₁=90, c₁=60, mass m₁): I₁xx_com = m₁(b₁² + c₁²)/12 = m₁(90² + 60²)/12 = m₁(8100 + 3600)/12 = 11700m₁/12 = 975m₁ mm²
I₁yy_com = m₁(a₁² + c₁²)/12 = m₁(55² + 60²)/12 = m₁(3025 + 3600)/12 = 6625m₁/12 = 552.08m₁ mm² I₁zz_com = m₁(a₁² + b₁²)/12 = m₁(55² + 90²)/12 = m₁(3025 + 8100)/12 = 11125m₁/12 = 927.08m₁ mm²

I₁_com = [

975m₁ | 0 | 0
0 | 552.08m₁ | 0
0 | 0 | 927.08m₁

]

Parallel-Axis Theorem — shift from COM to bottom face (motor mount). The COM shifts downward along y by b₁/2 = 45 mm, so d = [0, 45, 0]ᵀ:
I₁xx = I₁xx_com + m₁ · (45²) = 975m₁ + 2025m₁ = 3000m₁ mm² I₁yy = I₁yy_com + 0 = 552.08m₁ mm² (sℎift is along y
⟹ Iyy uncℎanged)
I₁zz = I₁zz_com + m₁ · (45²) = 927.08m₁ + 2025m₁ = 2952.08m₁ mm²

I₁ = [

3000m₁ | 0 | 0
0 | 552.08m₁ | 0
0 | 0 | 2952.08m₁

]

Scalar effective inertia for dynamics: Joint 1 rotates about the y-axis, so the rotation axis normal is n₁ = [0,1,0]ᵀ:
I1 = n₁

ᵀ · I₁ · n₁ = I₁yy_com = 552.08 m₁ mm²

Inertia Tensor — Link 2

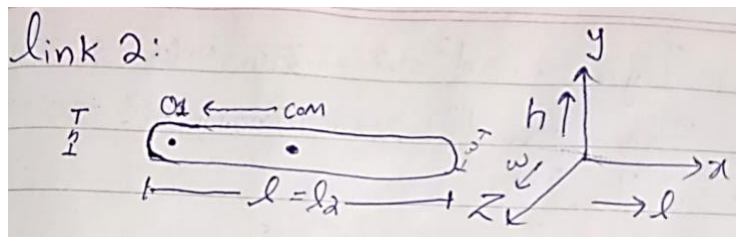
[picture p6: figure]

Link 2 is horizontal. Dimensions: a₂=210 mm (x, length), b₂=55 mm (y), c₂=60 mm (z).

I₂xx_com = m₂(b₂² + c₂²)/12 = m₂(55² + 60²)/12 = m₂(3025 + 3600)/12 = 552.08m₂ mm²
I₂yy_com = m₂(a₂² + c₂²)/12 = m₂(210² + 60²)/12 = m₂(44100 + 3600)/12 = 47700m₂/12 = 3975m₂ mm²
I₂zz_com = m₂(a₂² + b₂²)/12 = m₂(210² + 55²)/12 = m₂(44100 + 3025)/12 = 47125m₂/12 = 3927.08m₂ mm²

PAT — shift from COM to left end (Joint 2 mount) along x by a₂/2 = 105 mm. d = [105,0,0]ᵀ:
I₂xx = I₂xx_com = 552.08m₂ mm² | (sℎift along x ⟹ Ixx uncℎanged)
I₂yy = I₂yy_com + m₂ · (105²) = 3975m₂ + 11025m₂ = 15000m₂ mm² I₂zz = I₂zz_com + m₂ · (105²) = 3927.08m₂ + 11025m₂ = 14952.08m₂ mm²

I₂ = [

552.08m₂ | 0 | 0
0 | 15000m₂ | 0
0 | 0 | 14952.08m₂

]

Scalar effective inertia: Joint 2 rotates about the z-axis, n₂ = [0,0,1]ᵀ: I2 = n₂

ᵀ · I₂ · n₂ = I₂zz = 14952.08 m₂ mm²

Inertia Tensor — Link 3

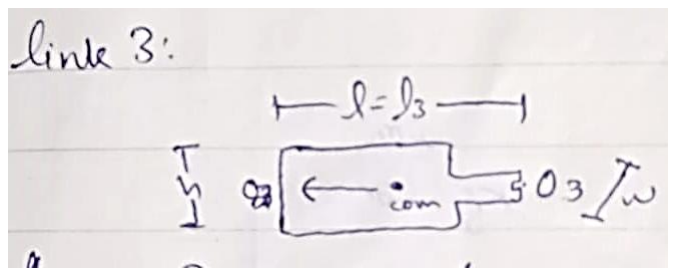
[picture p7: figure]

Link 3 is horizontal. Dimensions: a₃=170 mm (x), b₃=55 mm (y), c₃=60 mm (z).

I₃xx_com = m₃(55² + 60²)/12 = 552.08m₃ mm² I₃yy_com = m₃(170² + 60²)/12 = m₃(28900 + 3600)/12 = 32500m₃/12 = 2708.33m₃ mm²
I₃zz_com = m₃(170² + 55²)/12 = m₃(28900 + 3025)/12 = 31925m₃/12 = 2660.42m₃ mm²

PAT — shift from COM to left end (Joint 3 mount) along x by a₃/2 = 85 mm. d = [85,0,0]ᵀ:
I₃xx = 552.08m₃ mm² | (sℎift along x ⟹ Ixx uncℎanged)
I₃yy = 2708.33m₃ + m₃ · (85²) = 2708.33m₃ + 7225m₃ = 9933.33m₃ mm² I₃zz = 2660.42m₃ + m₃ · (85²) = 2660.42m₃ + 7225m₃ = 9885.42m₃ mm²

I₃ = [

552.08m₃ | 0 | 0
0 | 9933.33m₃ | 0
0 | 0 | 9885.42m₃

]

Scalar effective inertia: Joint 3 also rotates about z-axis, n₃ = [0,0,1]ᵀ: I3 = I₃zz = 9885.42 m₃ mm²

Table 4: Summary of Inertia Tensor Values at Motor Mount Points

Link | I_xx (mm²) | I_yy (mm²) | I_zz (mm²) | Scalar Iᵢ used in dynamics
Link 1 | 3000 m₁ | 552.08 m₁ (=I₁) | 2952.08 m₁ | I₁ = 552.08 m₁ (rot. about y)
Link 2 | 552.08 m₂ | 15000 m₂ | 14952.08 m₂ (=I₂) | I₂ = 14952.08 m₂ (rot. about z)
Link 3 | 552.08 m₃ | 9933.33 m₃ | 9885.42 m₃ (=I₃) | I₃ = 9885.42 m₃ (rot. about z)

Centre of Mass Positions

COM half-lengths: lc₁ = b₁/2 = 45 mm, lc₂ = a₂/2 = 105 mm, lc₃ = a₃/2 = 85 mm.

COM positions in the DH base frame:

C1 = [

0
0
lc₁

] = [

0
0/45]

(C₁ lies on the Z₀ axis — joint 1 rotation produces no linear velocity at this COM)

C2 = [

lc₂ c₁c₂
lc₂ s₁c₂
d₁ + lc₂ s₂

] = [

105c₁c₂
105s₁c₂
90 + 105s₂

]

Shorthand: Pc = l₂c₂ + lc₃c₂₃ = 210c₂ + 85c₂₃, Qc = l₂s₂ + lc₃s₂₃ = 210s₂ + 85s₂₃

C3 = [

c₁ · Pc
s₁ · Pc

90 + Qc] = [

c₁(210c₂ + 85c₂₃)
s₁(210c₂ + 85c₂₃)
90 + 210s₂ + 85s₂₃

]

COM Jacobians

The COM Jacobian for link i uses the same S(Z) method but targets Cᵢ instead of O₃. Columns after joint i are zero (joints beyond i do not move COM of link i).

JvC₁ and JωC₁ (Link 1 — column 1 only, rest zero)
Column 1: Jv₁_C₁ = S(Z₀)(C₁−O₀)
C₁ − O₀ = [0, 0, 45]ᵀ − [0, 0, 0]ᵀ = [0, 0, 45]ᵀ Row 1: (0)(0) + (−1)(0) + (0)(45) = 0 Row 2: (1)(0) + (0)(0) + (0)(45) = 0 Row 3: (0)(0) + (0)(0) + (0)(45) = 0
C₁ lies on the Z₀ axis ⟹ joint 1 rotation produces zero linear velocity at C₁.

JvC₁ = [

0 0 0
0 0 0
0 0 0

] JωC₁ = [

0 0 0
0 0 0
1 0 0

]

JvC₂ and JωC₂ (Link 2 — columns 1 and 2; column 3 = 0) Column 1: Jv₁_C₂ = S(Z₀)(C₂−O₀)
C₂ − O₀ = [105c₁c₂, 105s₁c₂, 90 + 105s₂]ᵀ Row 1: (0)(105c₁c₂) + (−1)(105s₁c₂) + (0)(90 + 105s₂) = −105s₁c₂ Row 2: (1)(105c₁c₂) + (0)(105s₁c₂) + (0)(90 + 105s₂) = 105c₁c₂

Row 3: (0)(105c₁c₂) + (0)(105s₁c₂) + (0)(90 + 105s₂) = 0

Column 2: Jv₂_C₂ = S(Z₁)(C₂−O₁) C₂ − O₁ = [105c₁c₂ − 0, 105s₁c₂ − 0, (90 + 105s₂) − 90]ᵀ
= [105c₁c₂, 105s₁c₂, 105s₂]ᵀ Row 1: (0)(105c₁c₂) + (0)(105s₁c₂) + (−c₁)(105s₂) = −105c₁s₂ Row 2: (0)(105c₁c₂) + (0)(105s₁c₂) + (−s₁)(105s₂) = −105s₁s₂ Row 3: (c₁)(105c₁c₂) + (s₁)(105s₁c₂) + (0)(105s₂) = 105c₂(c₁² + s₁²) = 105c₂

JvC₂ = [

−105s₁c₂ −105c₁s₂ 0
105c₁c₂ | −105s₁s₂ 0
0 | 105c₂ | 0

]

JωC₂ = [

0 | s₁ | 0
0 −c₁ 0
1 | 0 | 0

]

JvC₃ and JωC₃ (Link 3 — all three columns) Column 1: Jv₁_C₃ = S(Z₀)(C₃−O₀)
C₃ − O₀ = [c₁Pc, s₁Pc, 90 + Qc]ᵀ Row 1: (−1)(s₁Pc) = −s₁Pc
Row 2: (1)(c₁Pc) = c₁Pc
Row 3: 0

Column 2: Jv₂_C₃ = S(Z₁)(C₃−O₁) C₃ − O₁ = [c₁Pc, s₁Pc,Qc]ᵀ Row 1: (0)(c₁Pc) + (0)(s₁Pc) + (−c₁)(Qc) = −c₁Qc
Row 2: (0)(c₁Pc) + (0)(s₁Pc) + (−s₁)(Qc) = −s₁Qc
Row 3: (c₁)(c₁Pc) + (s₁)(s₁Pc) + (0)(Qc) = Pc(c₁² + s₁²) = Pc

Column 3: Jv₃_C₃ = S(Z₂)(C₃−O₂) C₃ − O₂ = [85c₁c₂₃, 85s₁c₂₃, 85s₂₃]ᵀ Row 1: (0)(85c₁c₂₃) + (0)(85s₁c₂₃) + (−c₁)(85s₂₃) = −85c₁s₂₃
Row 2: (0)(85c₁c₂₃) + (0)(85s₁c₂₃) + (−s₁)(85s₂₃) = −85s₁s₂₃
Row 3: (c₁)(85c₁c₂₃) + (s₁)(85s₁c₂₃) + (0)(85s₂₃) = 85c₂₃(c₁² + s₁²) = 85c₂₃

JvC₃ = [

−s₁Pc −c₁Qc −85c₁s₂₃
c₁Pc | −s₁Qc −85s₁s₂₃
0 | Pc | 85c₂₃ ]

JωC₃ = [

0 | s₁ | s₁
0 −c₁ | −c₁
1 | 0 | 0

]

Mass Matrix M(q)

The mass matrix is assembled from contributions of all three links: M(q) = Σᵢ [ mᵢ JvCᵢᵀ JvCᵢ + Iᵢ JωCᵢᵀ JωCᵢ ]

Link 1 Contribution
Since JvC₁ = 0, the translational part vanishes. Rotational part: JωC₁

ᵀ JωC₁ = [1,0,0; 0,0,0; 0,0,0] M_link1 = I₁ · [

1 0 0
0 0 0
0 0 0

] = [

I₁ 0 0
0 0 0
0 0 0

]

Link 2 Contribution
Translational part m₂ JvC₂ᵀ JvC₂:
(1,1): (−105s₁c₂)² + (105c₁c₂)² + 0 = 105²c₂²(s₁² + c₁²) = 105²c₂² = lc₂²c₂² (2,2): (−105c₁s₂)² + (−105s₁s₂)² + (105c₂)² = 105²s₂² + 105²c₂² = 105²
= lc₂²
(3,3): 0
(1,2): (−105s₁c₂)(−105c₁s₂) + (105c₁c₂)(−105s₁s₂) = 105²s₁c₁c₂s₂ − 105²c₁s₁s₂c₂ = 0

Rotational part I₂ JωC₂ᵀ JωC₂: JωC₂

ᵀ JωC₂ (1,1): 0² + 0² + 1² = 1, | (2,2): s₁² + c₁² = 1, | (3,3): 0,
off − diag: 0

M_link2 = m₂ [

lc₂²c₂² | 0 | 0
0 | lc₂² 0
0 | 0 | 0

] + I₂ [

1 0 0
0 1 0
0 0 0

]

Link 3 Contribution

Translational part m₃ JvC₃ᵀ JvC₃: (1,1): (−s₁Pc)² + (c₁Pc)² + 0 = Pc² (2,2): (−c₁Qc)² + (−s₁Qc)² + Pc² = Qc² + Pc² [note: Pc² + Qc² = 210² + 2 · 210 · 85c₃ + 85²] (3,3): (−85c₁s₂₃)² + (−85s₁s₂₃)² + (85c₂₃)² = 85²s₂₃² + 85²c₂₃² = 85² = lc₃² (2,3): (−c₁Qc)(−85c₁s₂₃) + (−s₁Qc)(−85s₁s₂₃) + (Pc)(85c₂₃) = 85Qcs₂₃(c₁² + s₁²) + 85Pcc₂₃
= 85[Qcs₂₃ + Pcc₂₃]
= 85[210(s₂s₂₃ + c₂c₂₃) + 85(s₂₃² + c₂₃²)] = 85[210cosθ₃ + 85] = 17850c₃ + 7225 = lc₃(l₂c₃ + lc₃) (1,2) = 0, (1,3) = 0

Rotational part I₃ JωC₃ᵀ JωC₃:
(1,1): 1, | (2,2): s₁² + c₁² = 1, | (3,3): s₁² + c₁² = 1,
(2,3) = s₁s₁ + c₁c₁ = 1

M_link3 = m₃ [
Pc² | 0 | 0
0 | Pc² + Qc² | 17850c₃ + 7225
0 | 17850c₃ + 7225 | 85² | ] + I₃ [
1 0 0
0 1 1
0 1 1

]

Final Mass Matrix M(q) = M_link1 + M_link2 + M_link3 M(q) = [

M₁₁ | 0 | 0
0 | M₂₂ M₂₃
0 | M₂₃ M₃₃]

where:
M₁₁ = I₁ + m₂ lc₂²c₂² + I₂ + m₃(l₂c₂ + lc₃c₂₃)² + I₃ M₂₂ = m₂ lc₂² + I₂ + m₃(l₂² + lc₃² + 2l₂lc₃c₃) + I₃ M₃₃ = m₃ lc₃² + I₃
M₂₃ = M₃₂ = m₃(lc₃² + l₂lc₃c₃) + I₃ M₁₂ = M₁₃ = 0

Kinetic Energy K

K =

1
2

θ̇ᵀ M(q) θ̇

Expanding step by step. First compute M(q)θ̇: M(q)θ̇ = [M₁₁θ̇₁, M₂₂θ̇₂ + M₂₃θ̇₃, M₂₃θ̇₂ + M₃₃θ̇₃]ᵀ

Then multiply by θ̇ᵀ:
K = ½[θ̇₁(M₁₁θ̇₁) + θ̇₂(M₂₂θ̇₂ + M₂₃θ̇₃) + θ̇₃(M₂₃θ̇₂ + M₃₃θ̇₃)]
= ½ M₁₁θ̇₁² + ½ M₂₂θ̇₂² + ½ M₂₃θ̇₂θ̇₃ + ½ M₂₃θ̇₃θ̇₂ + ½ M₃₃θ̇₃²
= ½ M₂₃θ̇₂θ̇₃ + ½ M₂₃θ̇₂θ̇₃ = M₂₃θ̇₂θ̇₃ [combining identical cross terms]

K =

1
2

M₁₁θ̇₁² +

1
2

M₂₂θ̇₂² + M₂₃θ̇₂θ̇₃ +

1
2

M₃₃θ̇₃²

Potential Energy U

Taking heights as the y (vertical) coordinate of each COM: ℎ₁ = lc₁ = 45 mm (constant) ℎ₂ = d₁ + lc₂ s₂ = 90 + 105s₂ ℎ₃ = d₁ + l₂ s₂ + lc₃ s₂₃ = 90 + 210s₂ + 85s₂₃

U = m₁ g lc₁ + m₂ g (d₁ + lc₂ s₂) + m₃ g (d₁ + l₂ s₂ + lc₃ s₂₃)

Lagrangian
L = K − U
L = ½M₁₁θ̇₁² + ½M₂₂θ̇₂² + M₂₃θ̇₂θ̇₃ + ½M₃₃θ̇₃² − m₁glc₁ − m₂g(d₁ + lc₂s₂) − m₃g(d₁ + l₂s₂ + lc₃s₂₃)

Derivation of τ₁

Lagrange equation:

τ1 =

d
dt (

∂L
∂θ̇₁

) −

∂L
∂θ₁
Step 1: ∂L/∂θ₁
Neither K nor U contain θ₁ explicitly (M₁₁, M₂₂, M₂₃, M₃₃ depend only on θ₂, θ₃; potential energy has no θ₁). Therefore:
∂L
∂θ₁

= 0

Step 2: ∂L/∂θ̇₁
∂L/∂θ̇₁ = M₁₁θ̇₁
Step 3: d/dt(M₁₁θ̇₁) — Product Rule d
dt (M₁₁θ̇₁) = Ṁ₁₁θ̇₁ + M₁₁θä₁
Step 4: Compute Ṁ₁₁

Recall M₁₁ = I₁ + I₂ + I₃ + m₂lc₂²c₂² + m₃(l₂c₂+lc₃c₂₃)². Constants vanish. Expanding (l₂c₂+lc₃c₂₃)²: = l₂²c₂² + 2l₂lc₃c₂c₂₃ + lc₃²c₂₃²

Variable terms: m₂lc₂²c₂², m₃l₂²c₂², 2m₃l₂lc₃c₂c₂₃, m₃lc₃²c₂₃²

Differentiating each term with ċ₂=−s₂θ̇₂ and ċ₂₃=−s₂₃(θ̇₂+θ̇₃): d/dt(m₂lc₂²c₂²) = −2m₂lc₂²c₂s₂θ̇₂ d/dt(m₃l₂²c₂²) = −2m₃l₂²c₂s₂θ̇₂ d/dt(2m₃l₂lc₃c₂c₂₃) = 2m₃l₂lc₃[ċ₂c₂₃ + c₂ċ₂₃] = 2m₃l₂lc₃[(−s₂θ̇₂)c₂₃ + c₂(−s₂₃)(θ̇₂ + θ̇₃)] = 2m₃l₂lc₃[−s₂c₂₃θ̇₂ − c₂s₂₃θ̇₂ − c₂s₂₃θ̇₃] = −2m₃l₂lc₃[(s₂c₂₃ + c₂s₂₃)θ̇₂ + c₂s₂₃θ̇₃] using identity s₂c₂₃ + c₂s₂₃ = s₂₃ = −2m₃l₂lc₃[s₂₃θ̇₂ + c₂s₂₃θ̇₃] d/dt(m₃lc₃²c₂₃²) = m₃lc₃² · 2c₂₃ · (−s₂₃)(θ̇₂ + θ̇₃) = −2m₃lc₃²c₂₃s₂₃(θ̇₂ + θ̇₃)

Collecting all terms:
Ṁ₁₁ = [−2m₂lc₂²c₂s₂ − 2m₃l₂²c₂s₂ − 2m₃l₂lc₃s₂₃ − 2m₃lc₃²c₂₃s₂₃]θ̇₂
+ [−2m₃l₂lc₃c₂s₂₃ − 2m₃lc₃²c₂₃s₂₃]θ̇₃ = −2m₃(l₂c₂ + lc₃c₂₃)[l₂s₂θ̇₂ + lc₃s₂₃(θ̇₂ + θ̇₃)] − 2m₂lc₂²c₂s₂θ̇₂
Step 5: Final τ₁
τ1 = M₁₁θä₁
− 2m₂lc₂²c₂s₂ · θ̇₁θ̇₂
− 2m₃(l₂c₂ + lc₃c₂₃)l₂s₂ · θ̇₁θ̇₂ − 2m₃(l₂c₂ + lc₃c₂₃)lc₃s₂₃ · θ̇₁θ̇₂ − 2m₃(l₂c₂ + lc₃c₂₃)lc₃s₂₃ · θ̇₁θ̇₃

Derivation of τ₂

Step 1: ∂L/∂θ̇₂
∂L/∂θ̇₂ = M₂₂θ̇₂ + M₂₃θ̇₃
Step 2: d/dt(M₂₂θ̇₂ + M₂₃θ̇₃) — Product Rule on each term
Differentiating M₂₂ = m₂lc₂² + I₂ + m₃(l₂²+lc₃²+2l₂lc₃c₃) + I₃: only 2l₂lc₃c₃ varies. Ṁ₂₂ = m₃ · 2l₂lc₃ · (−s₃θ̇₃) = −2m₃l₂lc₃s₃θ̇₃ d/dt(M₂₂θ̇₂) = Ṁ₂₂θ̇₂ + M₂₂θä₂ = −2m₃l₂lc₃s₃θ̇₂θ̇₃ + M₂₂θä₂

Differentiating M₂₃ = m₃(lc₃²+l₂lc₃c₃)+I₃: only l₂lc₃c₃ varies. Ṁ₂₃ = m₃l₂lc₃ · (−s₃θ̇₃) = −m₃l₂lc₃s₃θ̇₃ d/dt(M₂₃θ̇₃) = Ṁ₂₃θ̇₃ + M₂₃θä₃ = −m₃l₂lc₃s₃θ̇₃² + M₂₃θä₃

Combining:
d/dt(∂L/∂θ̇₂) = M₂₂θä₂ + M₂₃θä₃ − 2m₃l₂lc₃s₃θ̇₂θ̇₃ − m₃l₂lc₃s₃θ̇₃²
Step 3: ∂L/∂θ₂
Only M₁₁ depends on θ₂:
∂K/∂θ₂ = ½(∂M₁₁/∂θ₂)θ̇₁²
∂M₁₁/∂θ₂ = −2m₂lc₂²c₂s₂ − 2m₃(l₂c₂ + lc₃c₂₃)(l₂s₂ + lc₃s₂₃) ∂U/∂θ₂ = m₂glc₂c₂ + m₃g(l₂c₂ + lc₃c₂₃)
Step 4: Final τ₂
τ2 = M₂₂θä₂ + M₂₃θä₃
− 2m₃l₂lc₃s₃ · θ̇₂θ̇₃
− m₃l₂lc₃s₃ · θ̇₃²
+ [m₂lc₂²c₂s₂ + m₃(l₂c₂ + lc₃c₂₃)(l₂s₂ + lc₃s₂₃)] · θ̇₁² + m₂glc₂c₂ + m₃g(l₂c₂ + lc₃c₂₃)

Derivation of τ₃

Step 1: ∂L/∂θ̇₃
∂L/∂θ̇₃ = M₂₃θ̇₂ + M₃₃θ̇₃

Step 2: d/dt(M₂₃θ̇₂ + M₃₃θ̇₃) d/dt(M₂₃θ̇₂) = Ṁ₂₃θ̇₂ + M₂₃θä₂ = −m₃l₂lc₃s₃θ̇₂θ̇₃ + M₂₃θä₂ d/dt(M₃₃θ̇₃) = Ṁ₃₃θ̇₃ + M₃₃θä₃ [M₃₃ = m₃lc₃² + I₃ = constant ⟹ Ṁ₃₃ = 0] = M₃₃θä₃
d/dt(∂L/∂θ̇₃) = M₂₃θä₂ + M₃₃θä₃ − m₃l₂lc₃s₃θ̇₂θ̇₃
Step 3: ∂L/∂θ₃
Three elements M₁₁, M₂₂, M₂₃ depend on θ₃: ∂K/∂θ₃ = ½(∂M₁₁/∂θ₃)θ̇₁² + ½(∂M₂₂/∂θ₃)θ̇₂² + (∂M₂₃/∂θ₃)θ̇₂θ̇₃ ∂M₁₁/∂θ₃ = −2m₃lc₃(l₂c₂ + lc₃c₂₃)s₂₃ ∂M₂₂/∂θ₃ = −2m₃l₂lc₃s₃
∂M₂₃/∂θ₃ = −m₃l₂lc₃s₃
∂U/∂θ₃ = m₃glc₃c₂₃
∂L/∂θ₃ = −m₃lc₃(l₂c₂ + lc₃c₂₃)s₂₃θ̇₁² − m₃l₂lc₃s₃θ̇₂² − m₃l₂lc₃s₃θ̇₂θ̇₃ − m₃glc₃c₂₃
Step 4: Combine — note θ̇₂θ̇₃ terms cancel From Step 2: −m₃l₂lc₃s₃θ̇₂θ̇₃

From Step 3 (negated): +m₃l₂lc₃s₃θ̇₂θ̇₃

Sum = 0 ⟹ θ̇₂θ̇₃ terms cancel exactly. ✓

Step 5: Final τ₃
τ3 = M₂₃θä₂ + M₃₃θä₃
+ m₃lc₃(l₂c₂ + lc₃c₂₃)s₂₃ · θ̇₁² + m₃l₂lc₃s₃ · θ̇₂²
+ m₃glc₃c₂₃

Extraction of M(q), B(q), C(q), G(q)
Velocity vectors: [̇q̇q] = [θ̇₁θ̇₂, θ̇₁θ̇₃, θ̇₂θ̇₃]ᵀ (mixed), [̇q²] = [θ̇₁², θ̇₂², θ̇₃²]ᵀ (squared)

Mass Matrix M(q) — from θä coefficients:
M(q) = [
M₁₁ | 0 | 0
0 | M₂₂ M₂₃
0 | M₂₃ M₃₃]

Coriolis Matrix B(q) — from mixed velocity products: B(q) = [

−2(m₂lc₂²c₂s₂ + m₃Pc · Qs) −2m₃Pc · lc₃s₂₃ | 0
0 | 0 | −2m₃l₂lc₃s₃
0 | 0 | 0

]

where Pc = l₂c₂+lc₃c₂₃ and Qs = l₂s₂+lc₃s₂₃

Centrifugal Matrix C(q) — from squared velocity terms:

C(q) = [

0 | 0 | 0
(m₂lc₂²c₂s₂ + m₃Pc · Qs) | 0 | −m₃l₂lc₃s₃
m₃lc₃Pc · s₂₃ | m₃l₂lc₃s₃ | 0

]

Gravity Vector G(q):

G(q) = [

0
m₂glc₂c₂ + m₃g(l₂c₂ + lc₃c₂₃)
m₃glc₃c₂₃ | ]

Note: G₁ = 0 because joint 1 rotates about the vertical axis and performs no work against gravity regardless of θ₁. This is physically consistent and serves as a verification checkpoint.

MATLAB Simulation and Validation:

Introduction

To verify the analytical derivations, a complete simulation model of the proposed 3DOF Articulated Manipulator was developed using MATLAB R2023a and the Robotics System Toolbox. The simulation environment was used to validate the kinematic model, Jacobian matrix, workspace, singularity analysis, and dynamic model before implementing the manipulator on physical hardware.

The simulation followed the same Denavit–Hartenberg (DH) parameters, physical dimensions, and mass properties used in the analytical derivations to ensure consistency between theory and implementation.

Robot Model Development

The first step involved creating a rigid body tree model of the manipulator using MATLAB. Three revolute joints were defined according to the standard DH convention.

The manipulator dimensions used in the simulation are:

- Base height = 90 mm
- Link 2 length = 210 mm

- Link 3 length = 170 mm

The home configuration selected for the project is [0

∘

, 45∘

, − 45∘
]

This configuration was intentionally selected because the original configuration [0

∘, 0

∘, 0
∘
]was
found to be singular during Jacobian analysis.

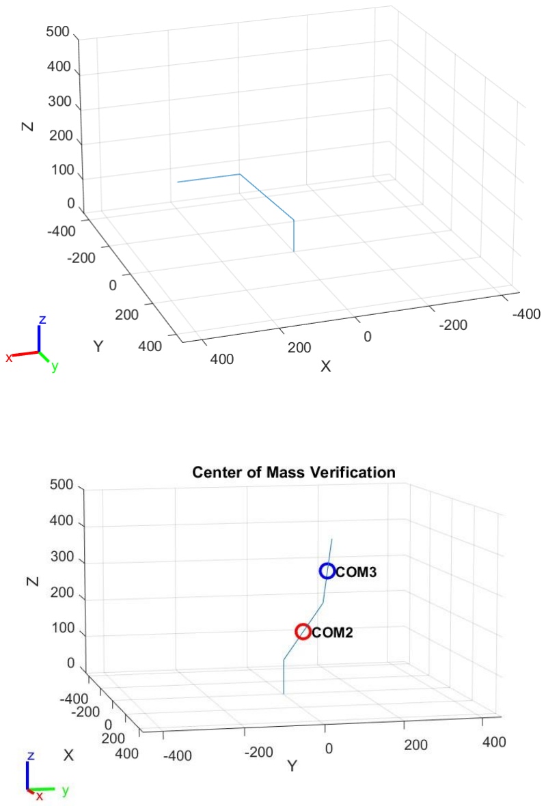
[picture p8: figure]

Workspace Analysis

The workspace of the manipulator was generated by sweeping all three joints within their allowable ranges.

Joint limits used during simulation were:

- Joint 1: 0° to 180°
- Joint 2: 0° to 180°
- Joint 3: –90° to +90°

The generated workspace illustrates all reachable end-effector positions.

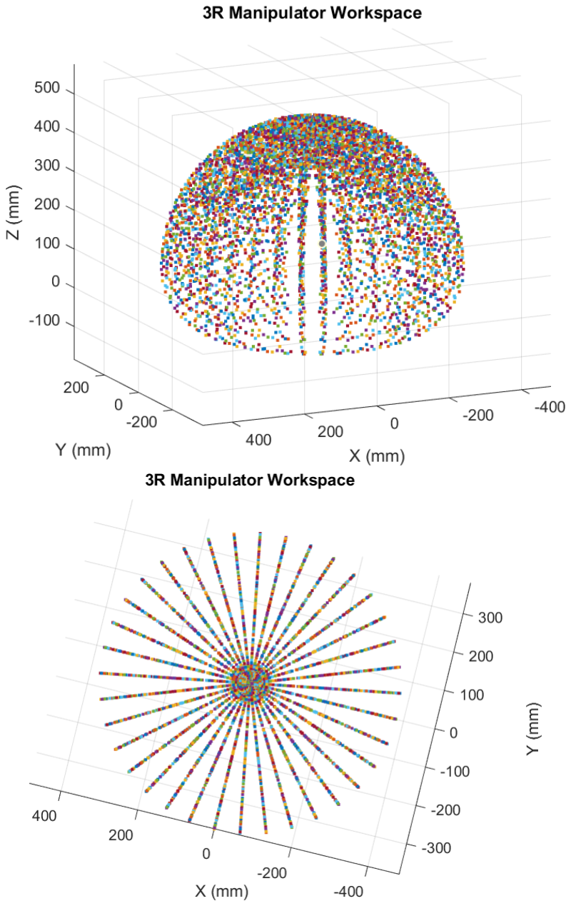
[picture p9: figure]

End-Effector Trajectory

A smooth trajectory was generated to observe the continuous movement of the end effector.

The trajectory remained continuous throughout the simulation without discontinuities, confirming that the analytical forward kinematics produced physically consistent motion.

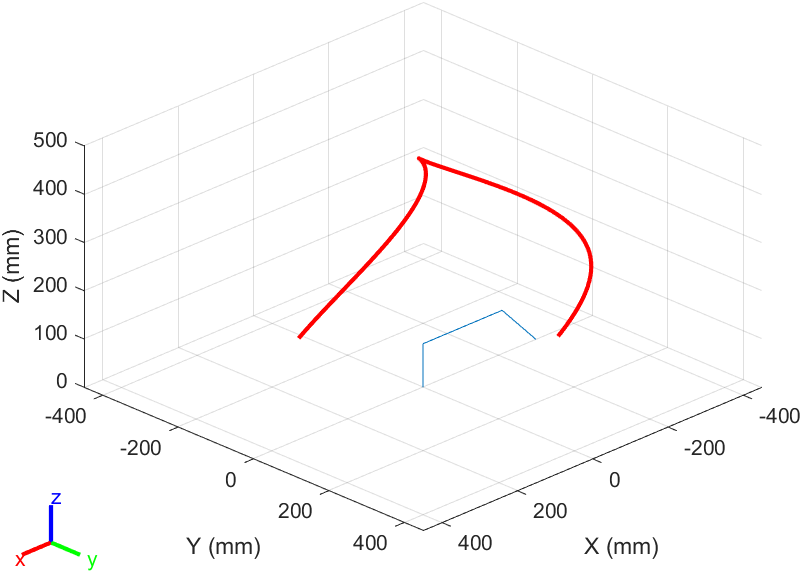
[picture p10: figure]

Workspace Manipulability Analysis

To evaluate dexterity throughout the workspace, the manipulability index w = √det(JvJv
T)

was calculated for a large number of reachable configurations.

A color-coded workspace map was generated in MATLAB, where larger values indicate higher dexterity and smaller values identify regions approaching singularities.

This visualization assists in selecting safe operating regions for trajectory planning and practical operation.

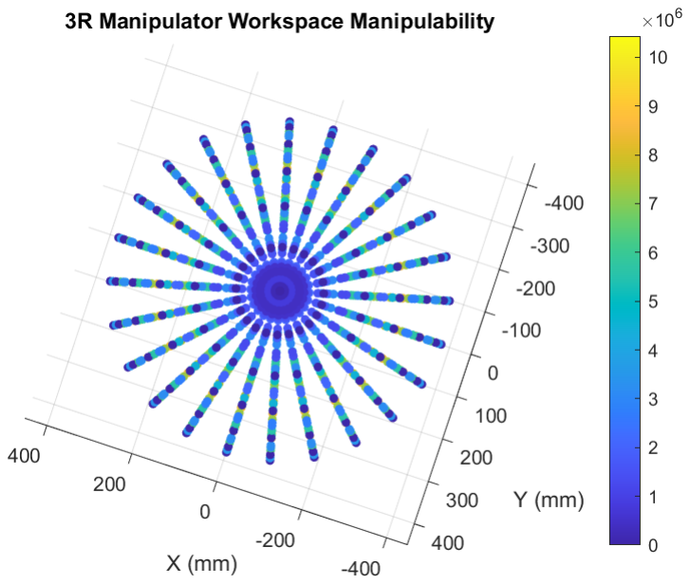
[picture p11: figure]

Dynamic Model Verification

The dynamic parameters obtained analytically were implemented in MATLAB.

The following quantities were evaluated:

- Mass matrix M(q)
- Gravity vector G(q)
- Joint torque equations
- Symmetry of the inertia matrix
- Positive definiteness of the inertia matrix

The simulation verified that:

- The mass matrix is symmetric.
- All eigenvalues are positive.
- The gravity vector agrees with the analytical model.
- The computed joint torques match the derived equations of motion.

Control:

Basic Revision

PID Controller

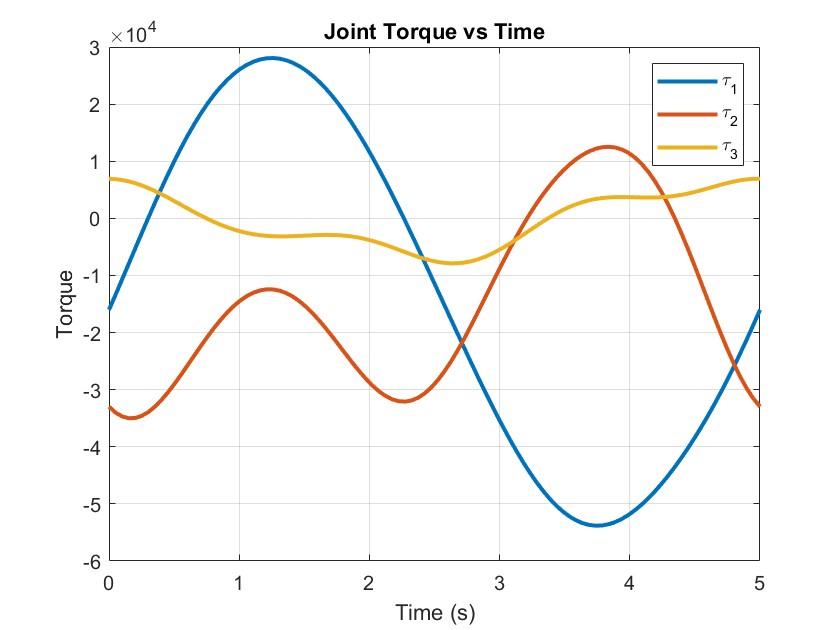
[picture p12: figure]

A Proportional-Integral-Derivative (PID) controller produces a control output u(t) from the joint angle error e(t) = θ_d(t) − θ(t):

u(t) = Kpe(t) + Ki∫ e(t)dt + Kd

de
dt

In discrete form (implemented on the ESP32 at sampling period Tₛ):

u[k] = Kpe[k] + KiTsΣe[k] + Kd

e[k] − e[k − 1)
Ts

State-Space Representation
Single-joint dynamics in state-space form with state x = [θ, θ̇]ᵀ:

ẋ = Ax + Bu, y = Cx
A = [

0 1
0 −b/J

], B = [ 01/J], C = [1 0]

where J is the effective moment of inertia at the joint and b is the viscous friction coefficient.

Robot Control Strategies

Joint-Space Control
The simplest strategy treats each joint independently with a PID loop. The ESP32 maps target angle to PWM pulse width linearly:

Pulse widtℎ (μs) = 500 +

θi
180°

× 2000

This approach ignores dynamic coupling between joints and is acceptable for slow, precise motions under light loading.

Computed Torque Method
The full dynamic model is inverted to linearise and decouple the system:

τ = M(q)(äq_d + Kdė + Kpe) + C(q, ̇q)̇q + G(q)

This cancels the nonlinear dynamics, reducing the closed-loop system to three decoupled linear second-order systems. Accurate values of M, C, G (requiring measured link masses) are needed.

Task-Space Control
The Cartesian position error drives the control via the Jacobian inverse:

̇q = J

v
⁻¹(ẋ_d + Kp(x_d − xe))

The pseudo-inverse Jᵥ⁺ = Jᵥᵀ(JᵥJᵥᵀ)⁻¹ is used near singular configurations. This strategy is preferred for straight-line trajectory tracking in Cartesian space.

Aurduino Implementation Notes
- PWM frame frequency: 50 Hz on all three servo channels.
- Pulse width range: 500 μs (0°) to 2500 μs (180°).
- Control loop runs on Core 1; serial communication and trajectory interpolation run on Core 0.
- The ledc peripheral provides 14-bit PWM resolution (≈0.01° per step).
- On power-up, all joints are driven to home position before accepting commands.
- Software joint-limit enforcement prevents commands outside the 0°–180° range.

### 9. Social and Economic Issues

### 9.1 Employment and Workforce Displacement

The increasing deployment of robotic manipulators in manufacturing and logistics raises concerns about workforce displacement. Repetitive assembly, welding, and pick-and-place tasks are most susceptible to automation. While robots reduce unit production cost and improve repeatability, they can displace semi-skilled workers in the short term. The economic consensus favours net long-term job creation through new industries such as robot manufacturing, programming, and maintenance, but the transition period requires retraining programmes and active policy support.

### 9.2 Safety

Robotic manipulators pose physical hazards including collision, pinch-point injuries, and unpredictable motion during faults. International standards (ISO 10218, ISO/TS 15066) mandate safety fencing, emergency stops, and force-torque limiting for collaborative robots. The 3R arm presented here operates at low torque (MG995 maximum 9.4 kg·cm) and low speed, placing it in the low-risk category. Safe operating zones, software joint-limit enforcement, and power-off-on-fault logic are implemented in the ESP32 firmware.

### 9.3 Economic Viability and Cost

A principal advantage of this design is its low cost relative to commercial 3-DOF arms. The bill of materials — three MG995 servos, acrylic sheet, ESP32 board, fasteners, and a power supply — totals approximately USD 15–25, compared with thousands of dollars for a commercial counterpart. This makes the platform accessible to university laboratories, STEM education programmes, and small-scale research groups in developing economies, democratising access to robotic manipulation technology.

### 9.4 Educational and Research Value

The project provides a tangible, hands-on platform for teaching kinematic theory (DH parameters, FK, IK), velocity analysis (Jacobian, singularities), and basic dynamics — concepts that are otherwise purely abstract in textbook form. Students engage directly with the gap between theoretical models and physical hardware constraints such as servo backlash, acrylic flex, and PWM resolution limitations.

### 9.5 Environmental Impact

Acrylic (PMMA) is a petrochemical-derived thermoplastic that is not readily biodegradable. Responsible disposal, recycling through specialist PMMA processors, or substitution with bio-based polymers should be considered at end-of-life. The low power consumption of the ESP32 and MG995 servos (total peak current below 3 A at 6 V, i.e. 18 W maximum) results in a minimal operational carbon footprint, especially when powered from renewable energy sources.

### 9.6 Intellectual Property and Open-Source Ethics

The design, firmware, and kinematic analysis developed in this project are intended for open academic dissemination. Sharing CAD files, MATLAB scripts, and Arduino code under an open-source licence (MIT or Creative Commons) promotes reproducibility and allows other researchers to build upon the work without intellectual property barriers — an important principle in publicly funded academic research.

References

[1] J. J. Craig, Introduction to Robotics: Mechanics and Control, 3rd ed. Pearson Prentice Hall, 2004.
[2] B. Siciliano, L. Sciavicco, L. Villani and G. Oriolo, Robotics: Modelling, Planning and Control. Springer, 2009.
[3] M. W. Spong, S. Hutchinson and M. Vidyasagar, Robot Modeling and Control, 2nd ed. Wiley, 2020.
[4] Espressif Systems, ESP32 Technical Reference Manual, v5.1, 2023. [Online]. Available: https://docs.espressif.com
[5] Tower Pro, MG995 Metal Gear Servo Datasheet, 2020.
[6] ISO 10218-1:2011, Robots and Robotic Devices — Safety Requirements for Industrial Robots. ISO, Geneva, 2011.
[7] International Fede

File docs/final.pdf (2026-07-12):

3R (Articulated)

Key Characteristics:

The manipulator under study is a three-revolute-joint (3R) serial robotic arm. All three joints are actuated revolute joints, making this a fully rotational, open-chain mechanism with three degrees of freedom. The system is designed for educational demonstration of robotic kinematics, dynamics, and point-to-point positioning.

Table 1: Key Characteristics of the 3R Manipulator

Parameter | Value / Description
Configuration | RRR — three revolute joints connected in series (serial chain)
Degrees of Freedom (DOF) | 3
Joint 1 — θ₁ | Rotation about vertical Z₀ axis (base rotation), range: 0° – 180°
Joint 2 — θ₂ | Rotation about horizontal Z₁ axis (shoulder), range: 0° – 180°
Joint 3 — θ₃ | Rotation about Z₂ axis (elbow), range: 0° – 180°
Base Height (d₁) | 90 mm — vertical offset from ground to shoulder joint centre
Link 2 Length (l₂) | 210 mm
Link 3 Length (l₃) | 170 mm (includes end-effector structural body)
Maximum Vertical Reach | d₁ + l₂ + l₃ = 90 + 210 + 170 = 470 mm (arm fully extended upward, θ₂=90°, θ₃=0°)
Minimum Vertical Reach | d₁ + l₂ − l₃ = 90 + 210 − 170 = 130 mm (arm folded back, θ₂=90°, θ₃=180°)
End-Effector | Point at tip of Link 3 — no gripper; gripper profile is structural only
Actuators | MG995 Metal Gear Servo Motors × 3 — torque 9.4 kg·cm @ 6 V
Controller | ESP32 Microcontroller — PWM via ledc peripheral (14-bit resolution)
Link Material | Acrylic (PMMA) sheet — 5 mm thick, ρ ≈ 1180 kg/m³
Link Cross-Section | Width (z-axis) = 60 mm, Height (y-axis) = 55 mm for Links 2 & 3
Link 1 Cross-Section | Width (z-axis) = 60 mm, Horizontal (x-axis) = 55 mm, Height (y- axis) = 90 mm
Design Software | SolidWorks (3D CAD and assembly)
Analysis Software | MATLAB (kinematics simulation, workspace, plots)
Firmware IDE | Arduino IDE (ESP32 PWM servo control)

DH Frame Assignment

Coordinate frames are assigned following the standard Denavit-Hartenberg convention. The Z-axis of each frame coincides with the joint rotation axis. The symbol ⊗ in the design sketch denotes a Z-axis directed into the page. Z₀ points vertically upward. Z₁ and Z₂ are horizontal and parallel (both pointing out of the plane in the side-view sketch), consistent with α₁ = 90° at joint 1 and α₂ = α₃ = 0°.

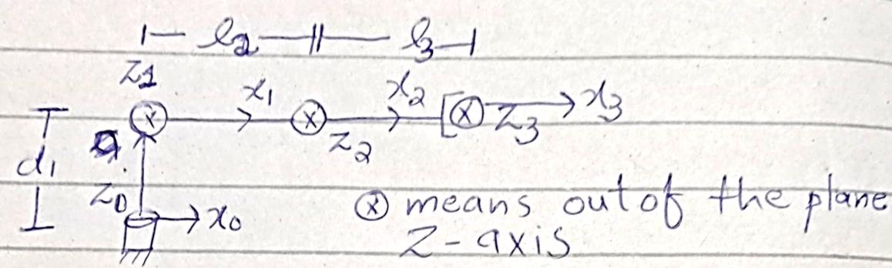
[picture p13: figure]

Figure 2: DH Frame Assignment Sketch — Side View showing Z₀, Z₁, Z₂ axes and O₀, O₁, O₂, O₃ origins

Home / Reference Configuration

Before executing any motion task, the manipulator is driven to a fixed reference pose known as the home configuration. This provides a consistent, safe starting state. The home joint angles are:

θ1 = 0° , θ2 = 0° , θ3 = 90°

Substituting into the forward kinematics (derived in Section 4): x = cos 0° · (210 cos 0° + 170 cos 90°) = 1 · (210 + 0) = 210 mm y = sin 0° · (210 cos 0° + 170 cos 90°) = 0 mm z = 90 + 210 sin 0° + 170 sin 90° = 90 + 0 + 170 = 260 mm

Home end-effector position: O₃ = (210, 0, 260) mm in the base frame.

Table 2: PWM Initialisation Values at Home Configuration

Joint | Home Angle | PWM Pulse Width
Joint 1 (θ₁) | 0° | 500 μs
Joint 2 (θ₂) | 0° | 500 μs

Joint 3 (θ₃) | 90° | 1500 μs

PWM frame frequency: 50 Hz. Range: 500 μs (0°) to 2500 μs (180°). On power-up, the ESP32 drives all channels to home values before accepting motion commands.

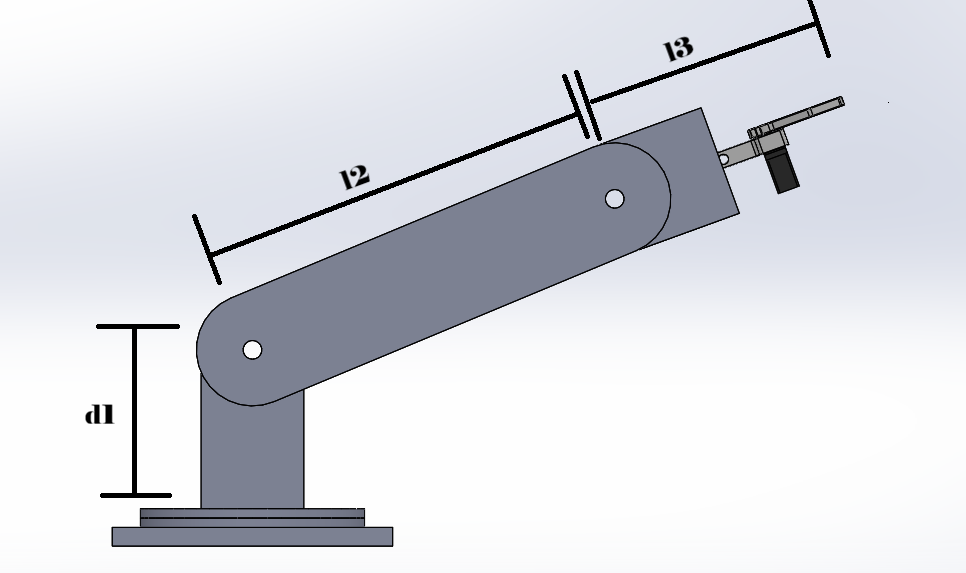
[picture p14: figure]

Homogeneous Transformation Matrices
A homogeneous transformation matrix T ∈ ℝ⁴ˣ⁴ encodes both the rotation and translation between two consecutive coordinate frames. Using the standard Denavit-Hartenberg convention, the transformation from frame i−1 to frame i is:

Tₘ = Rot(Z, θᵢ) · Trans(Z, dᵢ) · Trans(X, aᵢ) · Rot(X, αᵢ)

Expanding into 4×4 matrix form, where cθ = cosθ, sθ = sinθ, cα = cosα, sα = sinα:

Tᵢ = [

cθᵢ −sθᵢ cαᵢ | sθᵢ sαᵢ | aᵢ cθᵢ
sθᵢ cθᵢ cαᵢ | −cθᵢ sαᵢ aᵢ sθᵢ
0 | sαᵢ | cαᵢ | dᵢ
0 | 0 | 0 | 1

]

The shorthand notation cᵢ = cosθᵢ, sᵢ = sinθᵢ, c₂₃ = cos(θ₂+θ₃), s₂₃ = sin(θ₂+θ₃) is used throughout.

Individual Matrix ⁰T¹ (a₁=0, α₁=90°, d₁=90, θ₁)
Substituting a₁=0, α₁=90° ⟹ cosα₁=0, sinα₁=1, d₁=90 mm:

⁰T¹ = [

c₁ 0 | s₁ | 0
s₁ 0 | −c₁ | 0
0 | 1 | 0 | 90
0 | 0 | 0 | 1

]

Individual Matrix ¹T² (a₂=210, α₂=0°, d₂=0, θ₂) Substituting a₂=210 mm, α₂=0° ⟹ cosα₂=1, sinα₂=0, d₂=0:

¹T² = [

c₂ | −s₂ 0 210c₂
s₂ | c₂ | 0 210s₂
0 | 0 | 1 | 0
0 | 0 | 0 | 1

]

Individual Matrix ²T³ (a₃=170, α₃=0°, d₃=0, θ₃)

Substituting a₃=170 mm, α₃=0°, d₃=0:

²T³ = [

c₃ | −s₃ 0 170c₃
s₃ | c₃ | 0 170s₃
0 | 0 | 1 | 0
0 | 0 | 0 | 1

]

Cumulative Matrix ⁰T² = ⁰T¹ · ¹T²

Performing full row-by-column multiplication. Key element computations: R(1,1) = c₁ · c₂ + 0 · s₂ + s₁ · 0 = c₁c₂ R(2,1) = s₁ · c₂ + 0 · s₂ + (−c₁) · 0 = s₁c₂ R(3,1) = 0 · c₂ + 1 · s₂ + 0 · 0 = s₂ R(1,2) = c₁ · (−s₂) + 0 · c₂ + s₁ · 0 = −c₁s₂ R(1,3) = c₁ · 0 + 0 · 0 + s₁ · 1 = s₁ R(2,3) = s₁ · 0 + 0 · 0 + (−c₁) · 1 = −c₁
p_x = c₁ · 210c₂ + 0 · 210s₂ + s₁ · 0 + 0 = 210c₁c₂ p_y = s₁ · 210c₂ + 0 · 210s₂ + (−c₁) · 0 + 0 = 210s₁c₂ p_z = 0 · 210c₂ + 1 · 210s₂ + 0 · 0 + 90 = 210s₂ + 90

Full result:

⁰T² = [

c₁c₂ −c₁s₂ | s₁ | 210c₁c₂
s₁c₂ −s₁s₂ −c₁ | 210s₁c₂
s₂ | c₂ | 0 | 210s₂ + 90
0 | 0 | 0 | 1

]

Full End-Effector Transform ⁰T³ = ⁰T² · ²T³

Using the angle-sum identities: c₂c₃−s₂s₃ = c₂₃ and s₂c₃+c₂s₃ = s₂₃. Key element derivations: R(1,1) = c₁c₂ · c₃ + (−c₁s₂) · s₃ + s₁ · 0 = c₁(c₂c₃ − s₂s₃) = c₁c₂₃ R(1,2) = c₁c₂ · (−s₃) + (−c₁s₂) · c₃ = −c₁(c₂s₃ + s₂c₃) = −c₁s₂₃ R(2,1) = s₁c₂c₃ − s₁s₂s₃ = s₁c₂₃ R(3,1) = s₂c₃ + c₂s₃ = s₂₃ p_x = 170c₁c₂₃ + 210c₁c₂ = c₁(210c₂ + 170c₂₃)
p_y = 170s₁c₂₃ + 210s₁c₂ = s₁(210c₂ + 170c₂₃)
p_z = 170(s₂c₃ + c₂s₃) + 210s₂ + 90 = 90 + 210s₂ + 170s₂₃

Final result:
⁰T³ = [
c₁c₂₃ −c₁s₂₃ | s₁ | c₁(210c₂ + 170c₂₃)
s₁c₂₃ −s₁s₂₃ −c₁ | s₁(210c₂ + 170c₂₃)
s₂₃ | c₂₃ | 0 | 90 + 210s₂ + 170s₂₃
0 | 0 | 0 | 1

]

Forward Position Kinematics:

Forward kinematics maps a set of joint angles (θ₁, θ₂, θ₃) to the Cartesian position of the end-effector point O₃ in the base frame. The position is extracted from the fourth column of ⁰T³.

DH Parameter Table

Table 3: Denavit-Hartenberg Parameters

Joint i | aᵢ (mm) | αᵢ (deg) | dᵢ (mm) | θᵢ
1 | 0 | 90° | d₁ = 90 | θ₁* (0° – 180°)
2 | l₂ = 210 | 0° | 0 | θ₂* (0° – 180°)
3 | l₃ = 170 | 0° | 0 | θ₃* (180° – 180°)

The asterisk (*) marks the variable (active) parameter. All other entries per row are constant geometric properties of the link.

Forward Kinematics Equations
Extracting the position column of ⁰T³, the end-effector position O₃ = (x, y, z) in the base frame is:

x = c1 · ( 210c2 + 170c23 ) y = s1 · ( 210c2 + 170c23 ) z = 90 + 210s2 + 170s23

Physical interpretation: x and y share the same horizontal planar radius r = 210c₂ + 170c₂₃, scaled by cosθ₁ and sinθ₁ respectively. Joint 1 sweeps the arm through the horizontal plane; joints 2 and 3 control elevation.

Velocity Kinematics:

Velocity kinematics relates joint angular velocities to the end-effector linear and angular velocities through the Jacobian matrix. The instructor’s explicit geometric Jacobian method is followed throughout, using skew-symmetric matrix notation S(Z) in place of direct cross products.

Jacobian Method Overview

For each revolute joint i, the Jacobian column is: Jvi = S(Z i−1) · (O₃ − O i−1) [linear velocity contribution]
Jωi = Z i−1 | [angular velocity contribution]

where S(Z) is the skew-symmetric matrix of Z = [z_x, z_y, z_z]ᵀ:

S(Z) = [

0 | −z_z | z_y
z_z | 0 | −z_x
−z_y | z_x | 0

]

The end-effector position is denoted O₃ (not P). All subtractions O₃−Oᵢ are performed term-by-term without premature cancellation.

Step 1: Z-Axis Vectors (from ⁰Tᵢ rotation column 3) Z0 = [

0
0/1]

Z1 = Tℎird column of R in ⁰T¹ = [

s₁
−c₁
0

]

Z2 = Tℎird column of R in ⁰T² = [

s₁
−c₁
0

]

Note: Z₁ = Z₂ because α₂ = 0° introduces no twist between frames 1 and 2.

Step 2: Origin Vectors (from ⁰Tᵢ position column 4)
O0 = [

0
0/0]

O1 = [

0
0/90]

O2 = [

210c₁c₂
210s₁c₂
90 + 210s₂

]

O3 = [

c₁(210c₂ + 170c₂₃)
s₁(210c₂ + 170c₂₃)
90 + 210s₂ + 170s₂₃

]

Step 3: Skew-Symmetric Matrices S(Z)

S(Z₀): Z₀ = [0, 0, 1]ᵀ ⟹ z_x=0, z_y=0, z_z=1 S(Z₀) = [

0 −1 0
1 | 0 | 0
0 | 0 | 0

]

S(Z₁): Z₁ = [s₁, −c₁, 0]ᵀ ⟹ z_x=s₁, z_y=−c₁, z_z=0 S(Z₁) = [

0 | 0 −c₁
0 | 0 −s₁
c₁ s₁ | 0

]

S(Z₂) = S(Z₁) (same vector) S(Z₂) = [

0 | 0 −c₁
0 | 0 −s₁
c₁ s₁ | 0

]

O₃ − Oᵢ Subtractions (term by term, no premature cancellation)

Define shorthand: P = 210c₂ + 170c₂₃ and Q = 210s₂ + 170s₂₃.

O₃ − O₀
Row 1: c₁P − 0 = c₁P
Row 2: s₁P − 0 = s₁P
Row 3: (90 + Q) − 0 = 90 + Q O3 − O0 = [

c₁P
s₁P
90 + Q

]

O₃ − O₁
Row 1: c₁P − 0 = c₁P
Row 2: s₁P − 0 = s₁P
Row 3: (90 + Q) − 90 = Q
O3 − O1 = [

c₁P
s₁P
Q

]

O₃ − O₂
Row 1: c₁(210c₂ + 170c₂₃) − 210c₁c₂ = 210c₁c₂ + 170c₁c₂₃ − 210c₁c₂ = (210c₁c₂ − 210c₁c₂) + 170c₁c₂₃ = 170c₁c₂₃ Row 2: s₁(210c₂ + 170c₂₃) − 210s₁c₂ = (210s₁c₂ − 210s₁c₂) + 170s₁c₂₃ = 170s₁c₂₃
Row 3: (90 + Q) − (90 + 210s₂) = (90 − 90) + (210s₂ + 170s₂₃ − 210s₂) = (210s₂ − 210s₂) + 170s₂₃ = 170s₂₃ O3 − O2 = [

170c₁c₂₃
170s₁c₂₃

170s₂₃ ]

Step 5: Linear Jacobian Columns Jᵥᵢ = S(Zᵢ₋₁)(O₃−Oᵢ₋₁)

Column 1: Jᵥ₁ = S(Z₀)·(O₃−O₀)
Full row-by-row multiplication:
Row 1: (0)(c₁P) + (−1)(s₁P) + (0)(90 + Q) = −s₁P Row 2: (1)(c₁P) + (0)(s₁P) + (0)(90 + Q) = c₁P Row 3: (0)(c₁P) + (0)(s₁P) + (0)(90 + Q) = 0

Jv1 = [

−s₁P
c₁P
0

]

Column 2: Jᵥ₂ = S(Z₁)·(O₃−O₁)
Row 1: (0)(c₁P) + (0)(s₁P) + (−c₁)(Q) = −c₁Q Row 2: (0)(c₁P) + (0)(s₁P) + (−s₁)(Q) = −s₁Q Row 3: (c₁)(c₁P) + (s₁)(s₁P) + (0)(Q) = c₁²P + s₁²P = P(c₁² + s₁²) = P Jv2 = [

−c₁Q
−s₁Q
P

]

Column 3: Jᵥ₃ = S(Z₂)·(O₃−O₂) Row 1: (0)(170c₁c₂₃) + (0)(170s₁c₂₃) + (−c₁)(170s₂₃) = −170c₁s₂₃ Row 2: (0)(170c₁c₂₃) + (0)(170s₁c₂₃) + (−s₁)(170s₂₃) = −170s₁s₂₃ Row 3: (c₁)(170c₁c₂₃) + (s₁)(170s₁c₂₃) + (0)(170s₂₃) = 170c₂₃(c₁² + s₁²) = 170c₂₃
Jv3 = [

−170c₁s₂₃
−170s₁s₂₃

170c₂₃ ]

Step 6: Angular Jacobian Columns Jωᵢ = Zᵢ₋₁ Jω₁ = Z₀ = [0, 0, 1]ᵀ
Jω₂ = Z₁ = [s₁, −c₁, 0]ᵀ
Jω₃ = Z₂ = [s₁, −c₁, 0]ᵀ
Step 7: Full Geometric Jacobian J (6×3)

Assembling all columns, where P = 210c₂+170c₂₃ and Q = 210s₂+170s₂₃:

J =
[

−s₁P −c₁Q −170c₁s₂₃ ← v_x
c₁P | −s₁Q −170s₁s₂₃ ← v_y
0 | P | 170c₂₃ | ← v_z
0 | s₁ | s₁ | ← ω_x
0 | −c₁ | −c₁ | ← ω_y
1 | 0 | 0 | ← ω_z]

Analytical (Linear Velocity) Jacobian Jᵥ (3×3)

The upper 3×3 sub-matrix gives the linear velocity mapping ẋ = Jᵥ θ̇:

Jᵥ = [

−s₁P −c₁Q −170c₁s₂₃
c₁P | −s₁Q −170s₁s₂₃
0 | P | 170c₂₃ ]

Singularity Analysis

A singularity occurs when det(Jᵥ) = 0. The arm cannot generate velocity in all directions at such configurations.

Determinant Calculation — Cofactor Expansion Along Row 3 det(Jᵥ) = 0 · C₃₁ + P · C₃₂ + 170c₂₃ · C₃₃

Cofactor C₃₂:
C₃₂ = (−1)⁵ det[[−s₁P, −170c₁s₂₃],[c₁P, −170s₁s₂₃]] = −1 · [(−s₁P)(−170s₁s₂₃) − (−170c₁s₂₃)(c₁P)] = −1 · [170s₁²Ps₂₃ + 170c₁²Ps₂₃]
= −1 · 170Ps₂₃(s₁² + c₁²) = −170Ps₂₃

Cofactor C₃₃:
C₃₃ = (+1) det[[−s₁P, −c₁Q],[c₁P, −s₁Q]] = (−s₁P)(−s₁Q) − (−c₁Q)(c₁P)
= s₁²PQ + c₁²PQ = PQ(s₁² + c₁²) = PQ

Substituting:
det(Jᵥ) = P · (−170Ps₂₃) + 170c₂₃ · PQ
= 170P(−Ps₂₃ + Qc₂₃)
= 170P[c₂₃(210s₂ + 170s₂₃) − s₂₃(210c₂ + 170c₂₃)] = 170P · 210[c₂₃s₂ − s₂₃c₂]
= 170 · 210 · P · sin(θ₂ − (θ₂ + θ₃)) = −35700 · P · sinθ₃

det(Jᵥ) = −35700 · (210c₂ + 170c₂₃) · sinθ₃

Singular Configurations
Singularity 1 — Elbow Singularity: sinθ₃ = 0 ⟹ θ₃ = 0° or θ₃ = 180°

At θ₃=0° the arm is fully extended; at θ₃=180° it is fully folded. Joints 2 and 3 become collinear and lose one independent control direction in the (r,z) plane.

Singularity 2 — Workspace Boundary:
P = 0 ⟹ 210c₂ + 170c₂₃ = 0

The end-effector lies on the vertical Z₀ axis (r = 0). The azimuthal angle θ₁ is undefined and joint 1 becomes singular. Any θ₁ can produce the same x=y=0 position.

Dynamics:

The equation of motion of the 3R manipulator, derived from the Euler-Lagrange formulation, is: M(q)äq + B(q)[̇q̇q] + C(q)[̇q²] + G(q) = τ

where q = [θ₁,θ₂,θ₃]ᵀ is the joint vector, M(q) is the 3×3 symmetric mass matrix, B(q) is the Coriolis matrix, C(q) is the centrifugal matrix, G(q) is the gravity vector, and τ is the joint torque vector.

Inertia Tensor — Link 1

Link 1 is the vertical column. Its dimensions in the Cartesian frame are:

- a₁ = 55 mm (along x, horizontal)
- b₁ = 90 mm (along y, vertical — this is the link length)
- c₁ = 60 mm (along z, out of plane)

The inertia tensor at the centre of mass (COM), derived by direct triple integration over limits −a₁/2 to a₁/2 in x, −b₁/2 to b₁/2 in y, −c₁/2 to c₁/2 in z:

General derivation of I_xx (same procedure for other components):
Ixx = ρ ∫ ∫ ∫ (y² + z²) dV
= ρ ∫ ₋¹/²ᵃ ∫ ₋ᵇ/²ᵇ/² ∫ ₋ᶜ/²ᶜ/² (y² + z²) dz dy dx = ρ · a · ∫ ₋ᵇ/²ᵇ/² [y²z + z³/3]₋ᶜ/²ᶜ/² dy = ρ · a · ∫ ₋ᵇ/²ᵇ/² (y²c + c³/12) dy
= ρ · a · [cy³/3 + c³y/12]₋ᵇ/²ᵇ/²
= ρ · a · (cb³/12 + c³b/12) = ρ · abc · (b² + c²)/12 = m(b² + c²)/12

Applying to Link 1 (a₁=55, b₁=90, c₁=60, mass m₁): I₁xx_com = m₁(b₁² + c₁²)/12 = m₁(90² + 60²)/12 = m₁(8100 + 3600)/12 = 11700m₁/12 = 975m₁ mm²

I₁yy_com = m₁(a₁² + c₁²)/12 = m₁(55² + 60²)/12 = m₁(3025 + 3600)/12 = 6625m₁/12 = 552.08m₁ mm² I₁zz_com = m₁(a₁² + b₁²)/12 = m₁(55² + 90²)/12 = m₁(3025 + 8100)/12 = 11125m₁/12 = 927.08m₁ mm²

I₁_com = [

975m₁ | 0 | 0
0 | 552.08m₁ | 0
0 | 0 | 927.08m₁

]

Parallel-Axis Theorem — shift from COM to bottom face (motor mount). The COM shifts downward along y by b₁/2 = 45 mm, so d = [0, 45, 0]ᵀ:
I₁xx = I₁xx_com + m₁ · (45²) = 975m₁ + 2025m₁ = 3000m₁ mm² I₁yy = I₁yy_com + 0 = 552.08m₁ mm² (sℎift is along y
⟹ Iyy uncℎanged)
I₁zz = I₁zz_com + m₁ · (45²) = 927.08m₁ + 2025m₁ = 2952.08m₁ mm²

I₁ = [

3000m₁ | 0 | 0
0 | 552.08m₁ | 0
0 | 0 | 2952.08m₁

]

Scalar effective inertia for dynamics: Joint 1 rotates about the y-axis, so the rotation axis normal is n₁ = [0,1,0]ᵀ:
I1 = n₁

ᵀ · I₁ · n₁ = I₁yy_com = 552.08 m₁ mm²

Inertia Tensor — Link 2

Link 2 is horizontal. Dimensions: a₂=210 mm (x, length), b₂=55 mm (y), c₂=60 mm (z).

I₂xx_com = m₂(b₂² + c₂²)/12 = m₂(55² + 60²)/12 = m₂(3025 + 3600)/12 = 552.08m₂ mm²
I₂yy_com = m₂(a₂² + c₂²)/12 = m₂(210² + 60²)/12 = m₂(44100 + 3600)/12 = 47700m₂/12 = 3975m₂ mm²
I₂zz_com = m₂(a₂² + b₂²)/12 = m₂(210² + 55²)/12 = m₂(44100 + 3025)/12 = 47125m₂/12 = 3927.08m₂ mm²

PAT — shift from COM to left end (Joint 2 mount) along x by a₂/2 = 105 mm. d = [105,0,0]ᵀ:
I₂xx = I₂xx_com = 552.08m₂ mm² | (sℎift along x ⟹ Ixx uncℎanged)
I₂yy = I₂yy_com + m₂ · (105²) = 3975m₂ + 11025m₂ = 15000m₂ mm²

I₂zz = I₂zz_com + m₂ · (105²) = 3927.08m₂ + 11025m₂ = 14952.08m₂ mm²

I₂ = [

552.08m₂ | 0 | 0
0 | 15000m₂ | 0
0 | 0 | 14952.08m₂

]

Scalar effective inertia: Joint 2 rotates about the z-axis, n₂ = [0,0,1]ᵀ: I2 = n₂

ᵀ · I₂ · n₂ = I₂zz = 14952.08 m₂ mm²

Inertia Tensor — Link 3

Link 3 is horizontal. Dimensions: a₃=170 mm (x), b₃=55 mm (y), c₃=60 mm (z).

I₃xx_com = m₃(55² + 60²)/12 = 552.08m₃ mm² I₃yy_com = m₃(170² + 60²)/12 = m₃(28900 + 3600)/12 = 32500m₃/12 = 2708.33m₃ mm²
I₃zz_com = m₃(170² + 55²)/12 = m₃(28900 + 3025)/12 = 31925m₃/12 = 2660.42m₃ mm²

PAT — shift from COM to left end (Joint 3 mount) along x by a₃/2 = 85 mm. d = [85,0,0]ᵀ:
I₃xx = 552.08m₃ mm² | (sℎift along x ⟹ Ixx uncℎanged)
I₃yy = 2708.33m₃ + m₃ · (85²) = 2708.33m₃ + 7225m₃ = 9933.33m₃ mm² I₃zz = 2660.42m₃ + m₃ · (85²) = 2660.42m₃ + 7225m₃ = 9885.42m₃ mm²

I₃ = [

552.08m₃ | 0 | 0
0 | 9933.33m₃ | 0
0 | 0 | 9885.42m₃

]

Scalar effective inertia: Joint 3 also rotates about z-axis, n₃ = [0,0,1]ᵀ: I3 = I₃zz = 9885.42 m₃ mm²

Table 4: Summary of Inertia Tensor Values at Motor Mount Points

Link | I_xx (mm²) | I_yy (mm²) | I_zz (mm²) | Scalar Iᵢ used in dynamics
Link 1 | 3000 m₁ | 552.08 m₁ (=I₁) | 2952.08 m₁ | I₁ = 552.08 m₁ (rot. about y)
Link 2 | 552.08 m₂ | 15000 m₂ | 14952.08 m₂ (=I₂) | I₂ = 14952.08 m₂ (rot. about z)
Link 3 | 552.08 m₃ | 9933.33 m₃ | 9885.42 m₃ (=I₃) | I₃ = 9885.42 m₃ (rot. about z)

Centre of Mass Positions

COM half-lengths: lc₁ = b₁/2 = 45 mm, lc₂ = a₂/2 = 105 mm, lc₃ = a₃/2 = 85 mm.

COM positions in the DH base frame:
C1 = [

0
0
lc₁

] = [

0
0/45]

(C₁ lies on the Z₀ axis — joint 1 rotation produces no linear velocity at this COM)

C2 = [

lc₂ c₁c₂
lc₂ s₁c₂
d₁ + lc₂ s₂

] = [

105c₁c₂
105s₁c₂
90 + 105s₂

]

Shorthand: Pc = l₂c₂ + lc₃c₂₃ = 210c₂ + 85c₂₃, Qc = l₂s₂ + lc₃s₂₃ = 210s₂ + 85s₂₃

C3 = [

c₁ · Pc
s₁ · Pc

90 + Qc] = [

c₁(210c₂ + 85c₂₃)
s₁(210c₂ + 85c₂₃)
90 + 210s₂ + 85s₂₃

]

COM Jacobians

The COM Jacobian for link i uses the same S(Z) method but targets Cᵢ instead of O₃. Columns after joint i are zero (joints beyond i do not move COM of link i).

JvC₁ and JωC₁ (Link 1 — column 1 only, rest zero)
Column 1: Jv₁_C₁ = S(Z₀)(C₁−O₀)
C₁ − O₀ = [0, 0, 45]ᵀ − [0, 0, 0]ᵀ = [0, 0, 45]ᵀ Row 1: (0)(0) + (−1)(0) + (0)(45) = 0 Row 2: (1)(0) + (0)(0) + (0)(45) = 0 Row 3: (0)(0) + (0)(0) + (0)(45) = 0
C₁ lies on the Z₀ axis ⟹ joint 1 rotation produces zero linear velocity at C₁.

JvC₁ = [

0 0 0
0 0 0
0 0 0

] JωC₁ = [

0 0 0
0 0 0
1 0 0

]

JvC₂ and JωC₂ (Link 2 — columns 1 and 2; column 3 = 0) Column 1: Jv₁_C₂ = S(Z₀)(C₂−O₀)
C₂ − O₀ = [105c₁c₂, 105s₁c₂, 90 + 105s₂]ᵀ Row 1: (0)(105c₁c₂) + (−1)(105s₁c₂) + (0)(90 + 105s₂) = −105s₁c₂ Row 2: (1)(105c₁c₂) + (0)(105s₁c₂) + (0)(90 + 105s₂) = 105c₁c₂ Row 3: (0)(105c₁c₂) + (0)(105s₁c₂) + (0)(90 + 105s₂) = 0

Column 2: Jv₂_C₂ = S(Z₁)(C₂−O₁) C₂ − O₁ = [105c₁c₂ − 0, 105s₁c₂ − 0, (90 + 105s₂) − 90]ᵀ
= [105c₁c₂, 105s₁c₂, 105s₂]ᵀ Row 1: (0)(105c₁c₂) + (0)(105s₁c₂) + (−c₁)(105s₂) = −105c₁s₂ Row 2: (0)(105c₁c₂) + (0)(105s₁c₂) + (−s₁)(105s₂) = −105s₁s₂ Row 3: (c₁)(105c₁c₂) + (s₁)(105s₁c₂) + (0)(105s₂) = 105c₂(c₁² + s₁²) = 105c₂

JvC₂ = [

−105s₁c₂ −105c₁s₂ 0
105c₁c₂ | −105s₁s₂ 0
0 | 105c₂ | 0

]

JωC₂ = [

0 | s₁ | 0
0 −c₁ 0
1 | 0 | 0

]

JvC₃ and JωC₃ (Link 3 — all three columns) Column 1: Jv₁_C₃ = S(Z₀)(C₃−O₀)
C₃ − O₀ = [c₁Pc, s₁Pc, 90 + Qc]ᵀ Row 1: (−1)(s₁Pc) = −s₁Pc
Row 2: (1)(c₁Pc) = c₁Pc
Row 3: 0

Column 2: Jv₂_C₃ = S(Z₁)(C₃−O₁) C₃ − O₁ = [c₁Pc, s₁Pc,Qc]ᵀ Row 1: (0)(c₁Pc) + (0)(s₁Pc) + (−c₁)(Qc) = −c₁Qc
Row 2: (0)(c₁Pc) + (0)(s₁Pc) + (−s₁)(Qc) = −s₁Qc
Row 3: (c₁)(c₁Pc) + (s₁)(s₁Pc) + (0)(Qc) = Pc(c₁² + s₁²) = Pc

Column 3: Jv₃_C₃ = S(Z₂)(C₃−O₂) C₃ − O₂ = [85c₁c₂₃, 85s₁c₂₃, 85s₂₃]ᵀ

Row 1: (0)(85c₁c₂₃) + (0)(85s₁c₂₃) + (−c₁)(85s₂₃) = −85c₁s₂₃
Row 2: (0)(85c₁c₂₃) + (0)(85s₁c₂₃) + (−s₁)(85s₂₃) = −85s₁s₂₃
Row 3: (c₁)(85c₁c₂₃) + (s₁)(85s₁c₂₃) + (0)(85s₂₃) = 85c₂₃(c₁² + s₁²) = 85c₂₃

JvC₃ = [

−s₁Pc −c₁Qc −85c₁s₂₃
c₁Pc | −s₁Qc −85s₁s₂₃
0 | Pc | 85c₂₃ ]

JωC₃ = [

0 | s₁ | s₁
0 −c₁ | −c₁
1 | 0 | 0

]

Mass Matrix M(q)

The mass matrix is assembled from contributions of all three links: M(q) = Σᵢ [ mᵢ JvCᵢᵀ JvCᵢ + Iᵢ JωCᵢᵀ JωCᵢ ]

Link 1 Contribution
Since JvC₁ = 0, the translational part vanishes. Rotational part: JωC₁

ᵀ JωC₁ = [1,0,0; 0,0,0; 0,0,0] M_link1 = I₁ · [

1 0 0
0 0 0
0 0 0

] = [

I₁ 0 0
0 0 0
0 0 0

]

Link 2 Contribution
Translational part m₂ JvC₂ᵀ JvC₂:
(1,1): (−105s₁c₂)² + (105c₁c₂)² + 0 = 105²c₂²(s₁² + c₁²) = 105²c₂² = lc₂²c₂² (2,2): (−105c₁s₂)² + (−105s₁s₂)² + (105c₂)² = 105²s₂² + 105²c₂² = 105²
= lc₂²
(3,3): 0
(1,2): (−105s₁c₂)(−105c₁s₂) + (105c₁c₂)(−105s₁s₂) = 105²s₁c₁c₂s₂ − 105²c₁s₁s₂c₂ = 0

Rotational part I₂ JωC₂ᵀ JωC₂: JωC₂

ᵀ JωC₂ (1,1): 0² + 0² + 1² = 1, | (2,2): s₁² + c₁² = 1, | (3,3): 0,
off − diag: 0

M_link2 = m₂ [

lc₂²c₂² | 0 | 0
0 | lc₂² 0
0 | 0 | 0 ] + I₂ [

1 0 0
0 1 0
0 0 0

]

Link 3 Contribution
Translational part m₃ JvC₃ᵀ JvC₃: (1,1): (−s₁Pc)² + (c₁Pc)² + 0 = Pc² (2,2): (−c₁Qc)² + (−s₁Qc)² + Pc² = Qc² + Pc² [note: Pc² + Qc² = 210² + 2 · 210 · 85c₃ + 85²] (3,3): (−85c₁s₂₃)² + (−85s₁s₂₃)² + (85c₂₃)² = 85²s₂₃² + 85²c₂₃² = 85² = lc₃² (2,3): (−c₁Qc)(−85c₁s₂₃) + (−s₁Qc)(−85s₁s₂₃) + (Pc)(85c₂₃) = 85Qcs₂₃(c₁² + s₁²) + 85Pcc₂₃
= 85[Qcs₂₃ + Pcc₂₃]
= 85[210(s₂s₂₃ + c₂c₂₃) + 85(s₂₃² + c₂₃²)] = 85[210cosθ₃ + 85] = 17850c₃ + 7225 = lc₃(l₂c₃ + lc₃) (1,2) = 0, (1,3) = 0

Rotational part I₃ JωC₃ᵀ JωC₃:
(1,1): 1, | (2,2): s₁² + c₁² = 1, | (3,3): s₁² + c₁² = 1,
(2,3) = s₁s₁ + c₁c₁ = 1

M_link3 = m₃ [
Pc² | 0 | 0
0 | Pc² + Qc² | 17850c₃ + 7225
0 | 17850c₃ + 7225 | 85² | ] + I₃ [
1 0 0
0 1 1
0 1 1

]

Final Mass Matrix M(q) = M_link1 + M_link2 + M_link3 M(q) = [

M₁₁ | 0 | 0
0 | M₂₂ M₂₃
0 | M₂₃ M₃₃]

where:
M₁₁ = I₁ + m₂ lc₂²c₂² + I₂ + m₃(l₂c₂ + lc₃c₂₃)² + I₃ M₂₂ = m₂ lc₂² + I₂ + m₃(l₂² + lc₃² + 2l₂lc₃c₃) + I₃ M₃₃ = m₃ lc₃² + I₃
M₂₃ = M₃₂ = m₃(lc₃² + l₂lc₃c₃) + I₃ M₁₂ = M₁₃ = 0

Kinetic Energy K

K =

1
2

θ̇ᵀ M(q) θ̇

Expanding step by step. First compute M(q)θ̇: M(q)θ̇ = [M₁₁θ̇₁, M₂₂θ̇₂ + M₂₃θ̇₃, M₂₃θ̇₂ + M₃₃θ̇₃]ᵀ

Then multiply by θ̇ᵀ:
K = ½[θ̇₁(M₁₁θ̇₁) + θ̇₂(M₂₂θ̇₂ + M₂₃θ̇₃) + θ̇₃(M₂₃θ̇₂ + M₃₃θ̇₃)]
= ½ M₁₁θ̇₁² + ½ M₂₂θ̇₂² + ½ M₂₃θ̇₂θ̇₃ + ½ M₂₃θ̇₃θ̇₂ + ½ M₃₃θ̇₃²
= ½ M₂₃θ̇₂θ̇₃ + ½ M₂₃θ̇₂θ̇₃ = M₂₃θ̇₂θ̇₃ [combining identical cross terms]

K =

1
2

M₁₁θ̇₁² +

1
2

M₂₂θ̇₂² + M₂₃θ̇₂θ̇₃ +

1
2

M₃₃θ̇₃²

Potential Energy U

Taking heights as the y (vertical) coordinate of each COM: ℎ₁ = lc₁ = 45 mm (constant) ℎ₂ = d₁ + lc₂ s₂ = 90 + 105s₂ ℎ₃ = d₁ + l₂ s₂ + lc₃ s₂₃ = 90 + 210s₂ + 85s₂₃

U = m₁ g lc₁ + m₂ g (d₁ + lc₂ s₂) + m₃ g (d₁ + l₂ s₂ + lc₃ s₂₃)

Lagrangian
L = K − U
L = ½M₁₁θ̇₁² + ½M₂₂θ̇₂² + M₂₃θ̇₂θ̇₃ + ½M₃₃θ̇₃² − m₁glc₁ − m₂g(d₁ + lc₂s₂) − m₃g(d₁ + l₂s₂ + lc₃s₂₃)

Derivation of τ₁

Lagrange equation:

τ1 =

d
dt (

∂L
∂θ̇₁

) −

∂L
∂θ₁
Step 1: ∂L/∂θ₁

Neither K nor U contain θ₁ explicitly (M₁₁, M₂₂, M₂₃, M₃₃ depend only on θ₂, θ₃; potential energy has no θ₁). Therefore:
∂L
∂θ₁

= 0

Step 2: ∂L/∂θ̇₁
∂L/∂θ̇₁ = M₁₁θ̇₁
Step 3: d/dt(M₁₁θ̇₁) — Product Rule d
dt (M₁₁θ̇₁) = Ṁ₁₁θ̇₁ + M₁₁θä₁
Step 4: Compute Ṁ₁₁

Recall M₁₁ = I₁ + I₂ + I₃ + m₂lc₂²c₂² + m₃(l₂c₂+lc₃c₂₃)². Constants vanish. Expanding (l₂c₂+lc₃c₂₃)²: = l₂²c₂² + 2l₂lc₃c₂c₂₃ + lc₃²c₂₃²

Variable terms: m₂lc₂²c₂², m₃l₂²c₂², 2m₃l₂lc₃c₂c₂₃, m₃lc₃²c₂₃²

Differentiating each term with ċ₂=−s₂θ̇₂ and ċ₂₃=−s₂₃(θ̇₂+θ̇₃): d/dt(m₂lc₂²c₂²) = −2m₂lc₂²c₂s₂θ̇₂ d/dt(m₃l₂²c₂²) = −2m₃l₂²c₂s₂θ̇₂ d/dt(2m₃l₂lc₃c₂c₂₃) = 2m₃l₂lc₃[ċ₂c₂₃ + c₂ċ₂₃] = 2m₃l₂lc₃[(−s₂θ̇₂)c₂₃ + c₂(−s₂₃)(θ̇₂ + θ̇₃)] = 2m₃l₂lc₃[−s₂c₂₃θ̇₂ − c₂s₂₃θ̇₂ − c₂s₂₃θ̇₃] = −2m₃l₂lc₃[(s₂c₂₃ + c₂s₂₃)θ̇₂ + c₂s₂₃θ̇₃] using identity s₂c₂₃ + c₂s₂₃ = s₂₃ = −2m₃l₂lc₃[s₂₃θ̇₂ + c₂s₂₃θ̇₃] d/dt(m₃lc₃²c₂₃²) = m₃lc₃² · 2c₂₃ · (−s₂₃)(θ̇₂ + θ̇₃) = −2m₃lc₃²c₂₃s₂₃(θ̇₂ + θ̇₃)

Collecting all terms:
Ṁ₁₁ = [−2m₂lc₂²c₂s₂ − 2m₃l₂²c₂s₂ − 2m₃l₂lc₃s₂₃ − 2m₃lc₃²c₂₃s₂₃]θ̇₂
+ [−2m₃l₂lc₃c₂s₂₃ − 2m₃lc₃²c₂₃s₂₃]θ̇₃ = −2m₃(l₂c₂ + lc₃c₂₃)[l₂s₂θ̇₂ + lc₃s₂₃(θ̇₂ + θ̇₃)] − 2m₂lc₂²c₂s₂θ̇₂
Step 5: Final τ₁
τ1 = M₁₁θä₁

− 2m₂lc₂²c₂s₂ · θ̇₁θ̇₂
− 2m₃(l₂c₂ + lc₃c₂₃)l₂s₂ · θ̇₁θ̇₂ − 2m₃(l₂c₂ + lc₃c₂₃)lc₃s₂₃ · θ̇₁θ̇₂ − 2m₃(l₂c₂ + lc₃c₂₃)lc₃s₂₃ · θ̇₁θ̇₃

Derivation of τ₂

Step 1: ∂L/∂θ̇₂
∂L/∂θ̇₂ = M₂₂θ̇₂ + M₂₃θ̇₃
Step 2: d/dt(M₂₂θ̇₂ + M₂₃θ̇₃) — Product Rule on each term
Differentiating M₂₂ = m₂lc₂² + I₂ + m₃(l₂²+lc₃²+2l₂lc₃c₃) + I₃: only 2l₂lc₃c₃ varies. Ṁ₂₂ = m₃ · 2l₂lc₃ · (−s₃θ̇₃) = −2m₃l₂lc₃s₃θ̇₃ d/dt(M₂₂θ̇₂) = Ṁ₂₂θ̇₂ + M₂₂θä₂ = −2m₃l₂lc₃s₃θ̇₂θ̇₃ + M₂₂θä₂

Differentiating M₂₃ = m₃(lc₃²+l₂lc₃c₃)+I₃: only l₂lc₃c₃ varies. Ṁ₂₃ = m₃l₂lc₃ · (−s₃θ̇₃) = −m₃l₂lc₃s₃θ̇₃ d/dt(M₂₃θ̇₃) = Ṁ₂₃θ̇₃ + M₂₃θä₃ = −m₃l₂lc₃s₃θ̇₃² + M₂₃θä₃

Combining:
d/dt(∂L/∂θ̇₂) = M₂₂θä₂ + M₂₃θä₃ − 2m₃l₂lc₃s₃θ̇₂θ̇₃ − m₃l₂lc₃s₃θ̇₃²
Step 3: ∂L/∂θ₂
Only M₁₁ depends on θ₂:
∂K/∂θ₂ = ½(∂M₁₁/∂θ₂)θ̇₁²
∂M₁₁/∂θ₂ = −2m₂lc₂²c₂s₂ − 2m₃(l₂c₂ + lc₃c₂₃)(l₂s₂ + lc₃s₂₃) ∂U/∂θ₂ = m₂glc₂c₂ + m₃g(l₂c₂ + lc₃c₂₃)
Step 4: Final τ₂
τ2 = M₂₂θä₂ + M₂₃θä₃
− 2m₃l₂lc₃s₃ · θ̇₂θ̇₃
− m₃l₂lc₃s₃ · θ̇₃²
+ [m₂lc₂²c₂s₂ + m₃(l₂c₂ + lc₃c₂₃)(l₂s₂ + lc₃s₂₃)] · θ̇₁² + m₂glc₂c₂ + m₃g(l₂c₂ + lc₃c₂₃)

Derivation of τ₃

Step 1: ∂L/∂θ̇₃
∂L/∂θ̇₃ = M₂₃θ̇₂ + M₃₃θ̇₃
Step 2: d/dt(M₂₃θ̇₂ + M₃₃θ̇₃) d/dt(M₂₃θ̇₂) = Ṁ₂₃θ̇₂ + M₂₃θä₂ = −m₃l₂lc₃s₃θ̇₂θ̇₃ + M₂₃θä₂ d/dt(M₃₃θ̇₃) = Ṁ₃₃θ̇₃ + M₃₃θä₃ [M₃₃ = m₃lc₃² + I₃ = constant ⟹ Ṁ₃₃ = 0] = M₃₃θä₃
d/dt(∂L/∂θ̇₃) = M₂₃θä₂ + M₃₃θä₃ − m₃l₂lc₃s₃θ̇₂θ̇₃
Step 3: ∂L/∂θ₃
Three elements M₁₁, M₂₂, M₂₃ depend on θ₃: ∂K/∂θ₃ = ½(∂M₁₁/∂θ₃)θ̇₁² + ½(∂M₂₂/∂θ₃)θ̇₂² + (∂M₂₃/∂θ₃)θ̇₂θ̇₃ ∂M₁₁/∂θ₃ = −2m₃lc₃(l₂c₂ + lc₃c₂₃)s₂₃ ∂M₂₂/∂θ₃ = −2m₃l₂lc₃s₃
∂M₂₃/∂θ₃ = −m₃l₂lc₃s₃
∂U/∂θ₃ = m₃glc₃c₂₃
∂L/∂θ₃ = −m₃lc₃(l₂c₂ + lc₃c₂₃)s₂₃θ̇₁² − m₃l₂lc₃s₃θ̇₂² − m₃l₂lc₃s₃θ̇₂θ̇₃ − m₃glc₃c₂₃
Step 4: Combine — note θ̇₂θ̇₃ terms cancel From Step 2: −m₃l₂lc₃s₃θ̇₂θ̇₃

From Step 3 (negated): +m₃l₂lc₃s₃θ̇₂θ̇₃

Sum = 0 ⟹ θ̇₂θ̇₃ terms cancel exactly. ✓

Step 5: Final τ₃
τ3 = M₂₃θä₂ + M₃₃θä₃
+ m₃lc₃(l₂c₂ + lc₃c₂₃)s₂₃ · θ̇₁² + m₃l₂lc₃s₃ · θ̇₂²
+ m₃glc₃c₂₃

Extraction of M(q), B(q), C(q), G(q)
Velocity vectors: [̇q̇q] = [θ̇₁θ̇₂, θ̇₁θ̇₃, θ̇₂θ̇₃]ᵀ (mixed), [̇q²] = [θ̇₁², θ̇₂², θ̇₃²]ᵀ (squared)

Mass Matrix M(q) — from θä coefficients: M(q) = [

M₁₁ | 0 | 0
0 | M₂₂ M₂₃
0 | M₂₃ M₃₃]

Coriolis Matrix B(q) — from mixed velocity products:

B(q) = [

−2(m₂lc₂²c₂s₂ + m₃Pc · Qs) −2m₃Pc · lc₃s₂₃ | 0
0 | 0 | −2m₃l₂lc₃s₃
0 | 0 | 0

]

where Pc = l₂c₂+lc₃c₂₃ and Qs = l₂s₂+lc₃s₂₃

Centrifugal Matrix C(q) — from squared velocity terms:

C(q) = [

0 | 0 | 0
(m₂lc₂²c₂s₂ + m₃Pc · Qs) | 0 | −m₃l₂lc₃s₃
m₃lc₃Pc · s₂₃ | m₃l₂lc₃s₃ | 0

]

Gravity Vector G(q):

G(q) = [

0
m₂glc₂c₂ + m₃g(l₂c₂ + lc₃c₂₃)
m₃glc₃c₂₃ | ]

Note: G₁ = 0 because joint 1 rotates about the vertical axis and performs no work against gravity regardless of θ₁. This is physically consistent and serves as a verification checkpoint.Control

Basic Revision

PID Controller
A Proportional-Integral-Derivative (PID) controller produces a control output u(t) from joint angle error e(t) = θ_d(t) − θ(t):

u(t) = Kpe(t) + Ki∫ e(t)dt + Kd

de
dt

In discrete form (implemented on ESP32 at sampling period Tₛ):

u[k] = Kpe[k] + KiTsΣe[k] + Kd

e[k] − e[k − 1]
Ts

State-Space Representation
Single-joint dynamics in state-space form with state x = [θ, θ̇]ᵀ:

ẋ = Ax + Bu, y = Cx
A = [

0 1 0 − b/J
], B = [

0
1/J

], C = [1 0]

Robot Control Strategies

Joint-Space Control (Independent PID Loops)
The simplest strategy treats each joint independently. The ESP32 maps target angle to PWM pulse width:

Pulse widtℎ (μs) = 500 +

θi
180°

× 2000

Ignores coupling between joints. Suitable for slow, lightly loaded motion.

Computed Torque Method (Model-Based)
The full dynamic model is inverted to cancel nonlinearities:
τ = M(q)(θä_d + Kdė + Kpe) + B(q)[̇q̇q] + C(q)[̇q²] + G(q)

This reduces the closed-loop system to three decoupled linear second-order systems. Requires accurate mass values.

Task-Space Control
Position error in Cartesian space drives the joints via the Jacobian inverse:

θ̇ = J

v †
(ẋ_d + Kp(x_d − xe))

The pseudo-inverse Jᵥ⁺ = Jᵥᵀ(JᵥJᵥᵀ)⁻¹ is used near singularities. Preferred for Cartesian straight-line trajectories.

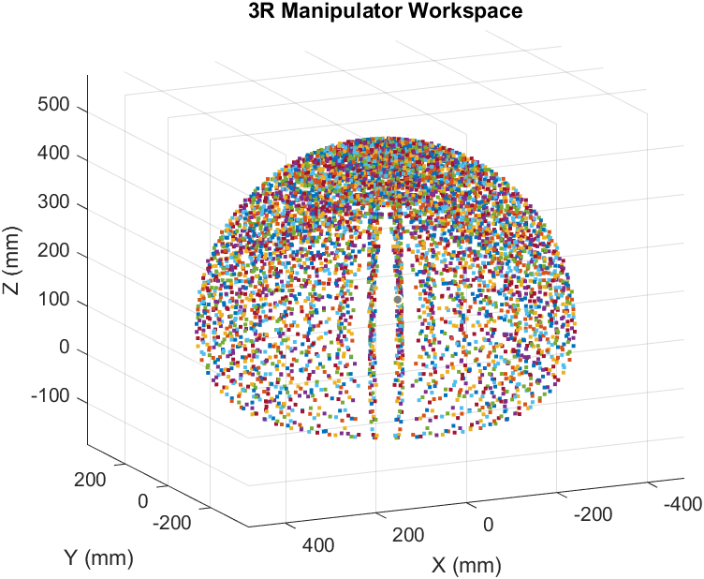
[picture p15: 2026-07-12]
media/untitled1.png

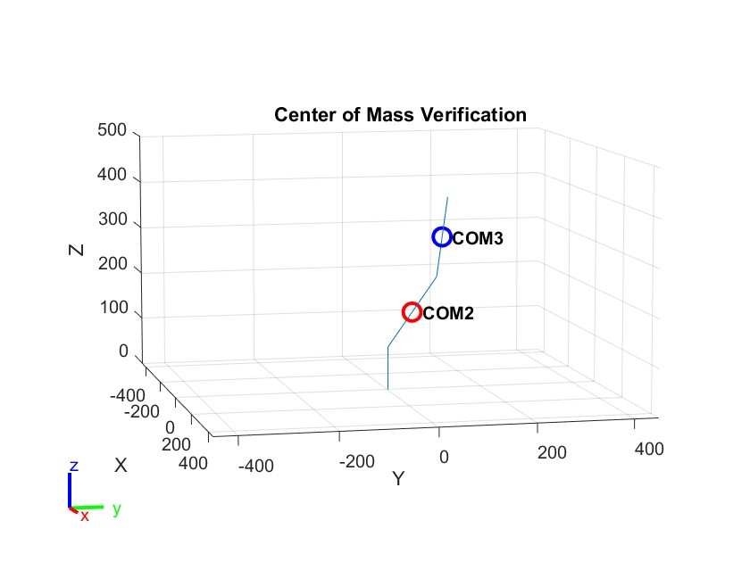
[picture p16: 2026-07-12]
media/untitled.jpg

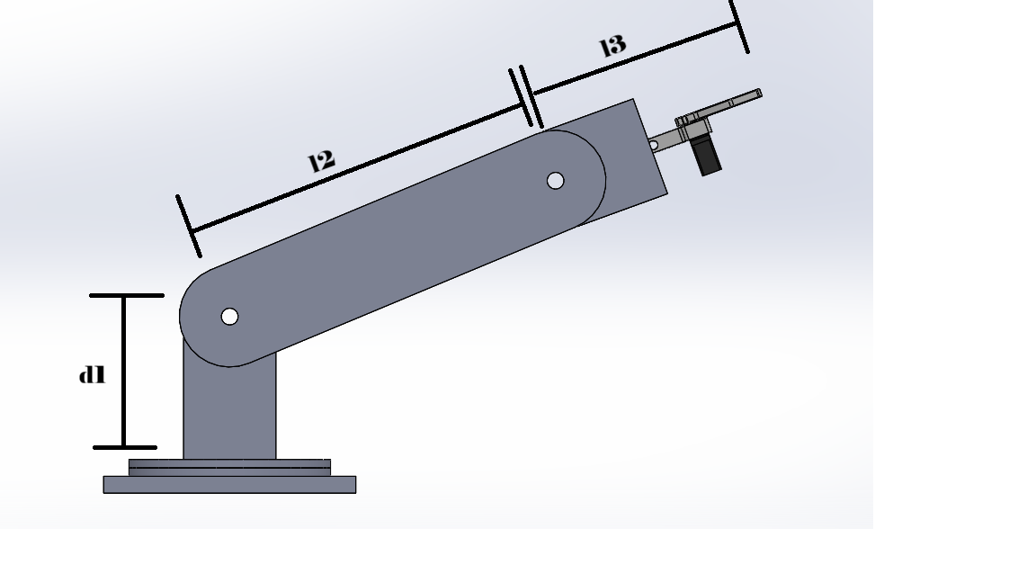
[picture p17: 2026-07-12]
media/tst.png

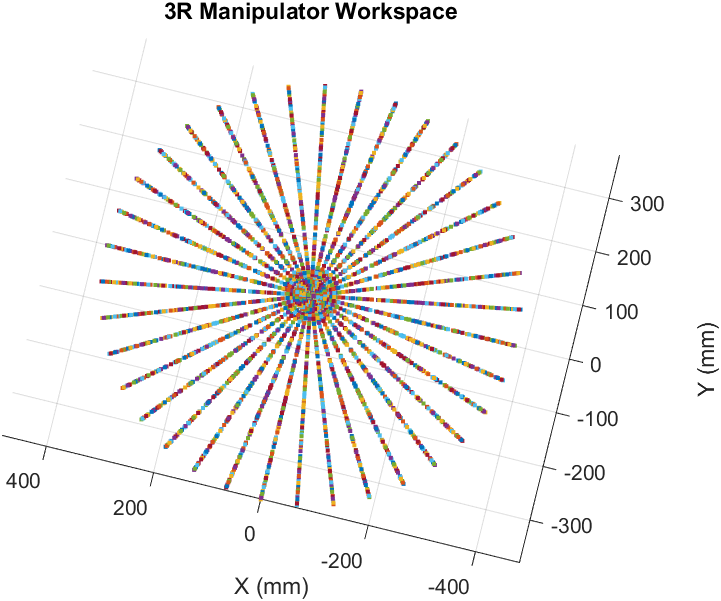
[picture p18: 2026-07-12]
media/untitled2.png

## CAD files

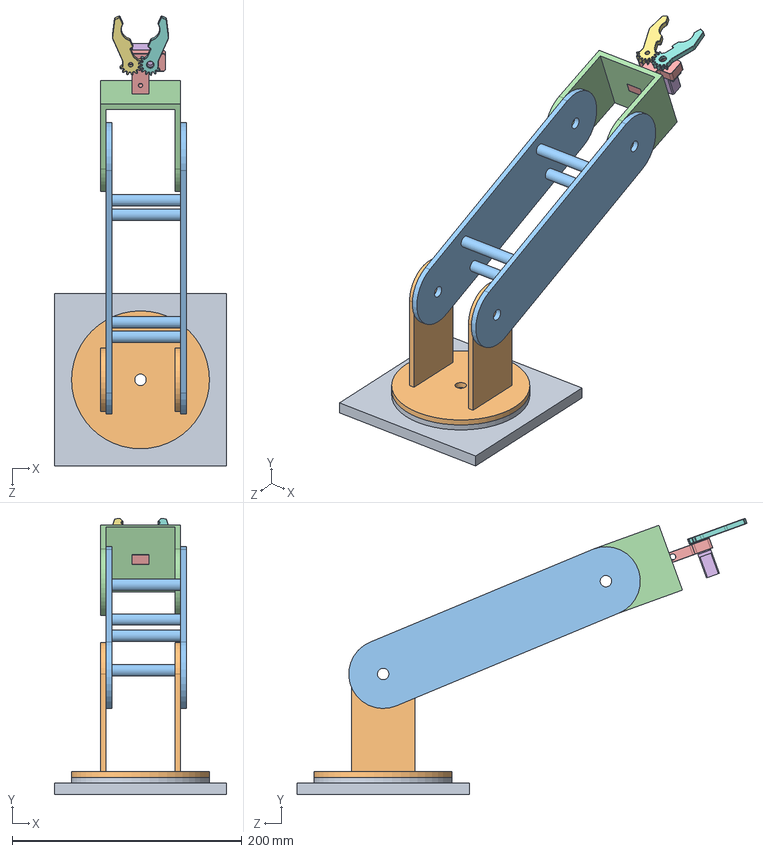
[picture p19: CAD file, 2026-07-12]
cad/3r arm.SLDASM
150.0 x 240.5 x 391.6 mm
base
link1
link2
link3
ad
mg90s1
27R
27L

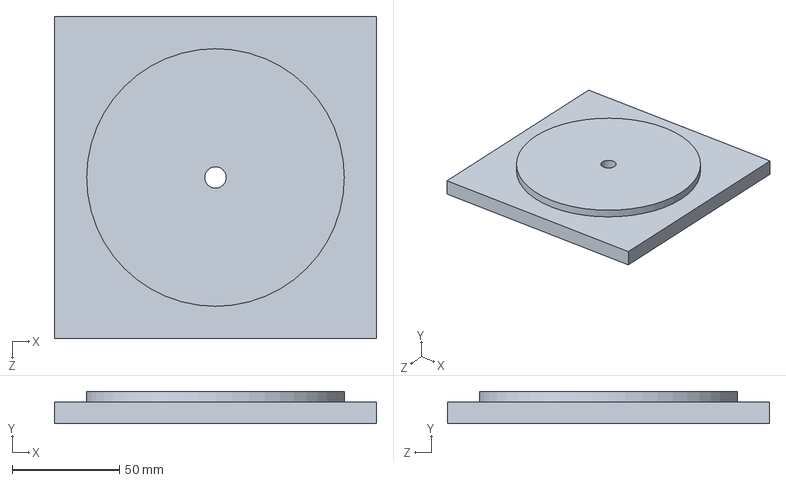
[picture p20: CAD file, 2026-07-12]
cad/base.SLDPRT
150.0 x 15.0 x 150.0 mm

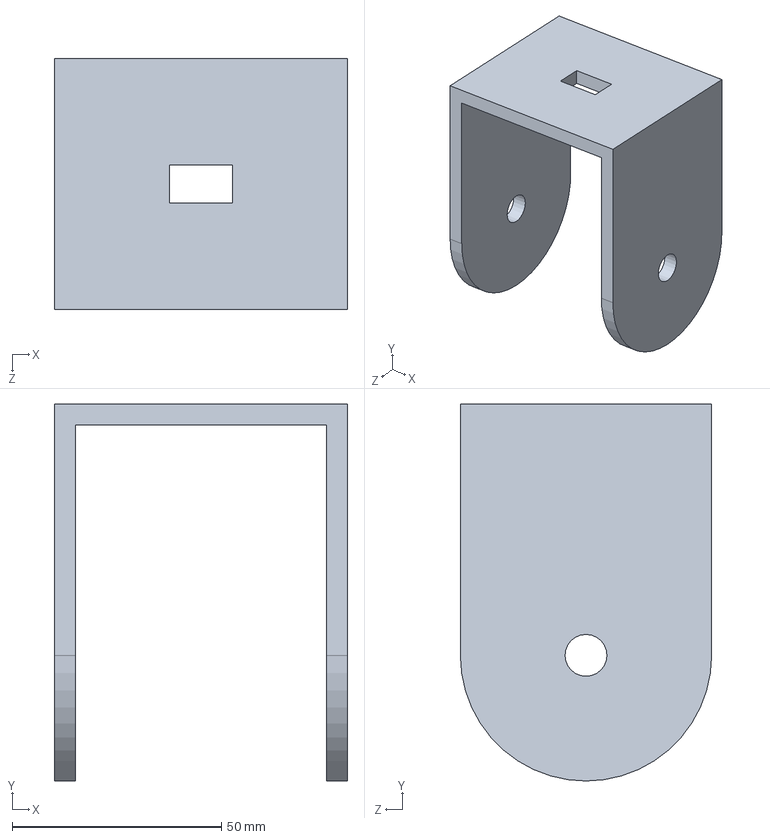
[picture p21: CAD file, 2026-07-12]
cad/link3.SLDPRT
70.0 x 90.0 x 60.0 mm

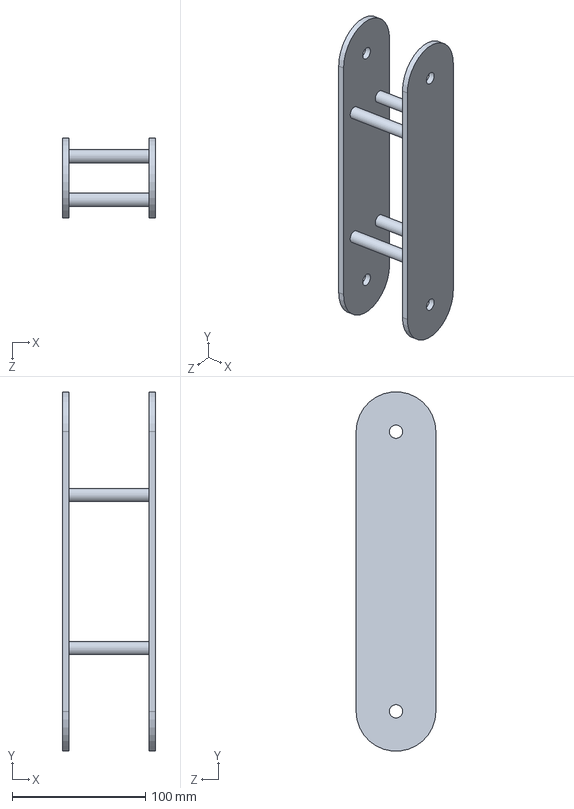
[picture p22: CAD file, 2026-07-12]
cad/link2.SLDPRT
70.0 x 269.7 x 60.0 mm

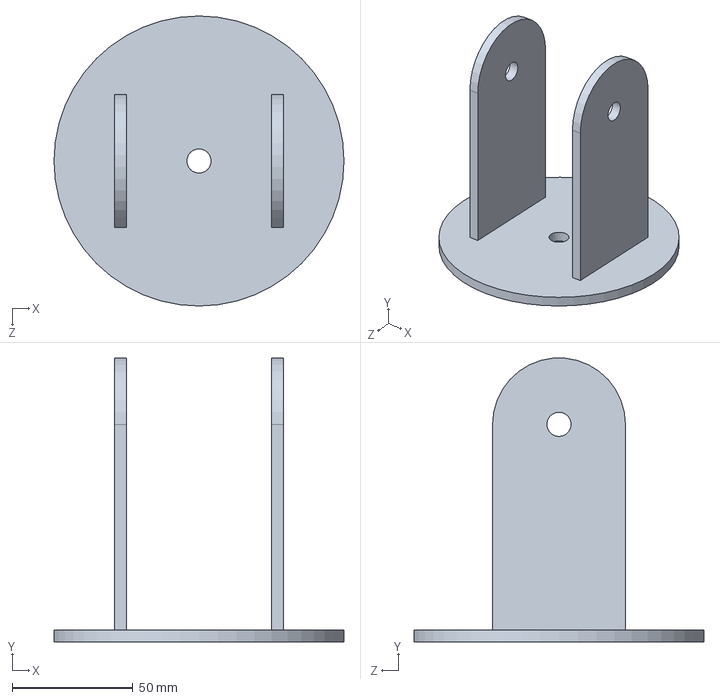
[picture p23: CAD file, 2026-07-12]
cad/link1.SLDPRT
120.0 x 117.4 x 120.0 mm

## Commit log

2026-07-12 Add files via upload
    Add MATLAB simulation, CAD files, and project report.
2026-07-12 Rename robotics arm model cad.rar to cad/robotics arm model cad.rar
